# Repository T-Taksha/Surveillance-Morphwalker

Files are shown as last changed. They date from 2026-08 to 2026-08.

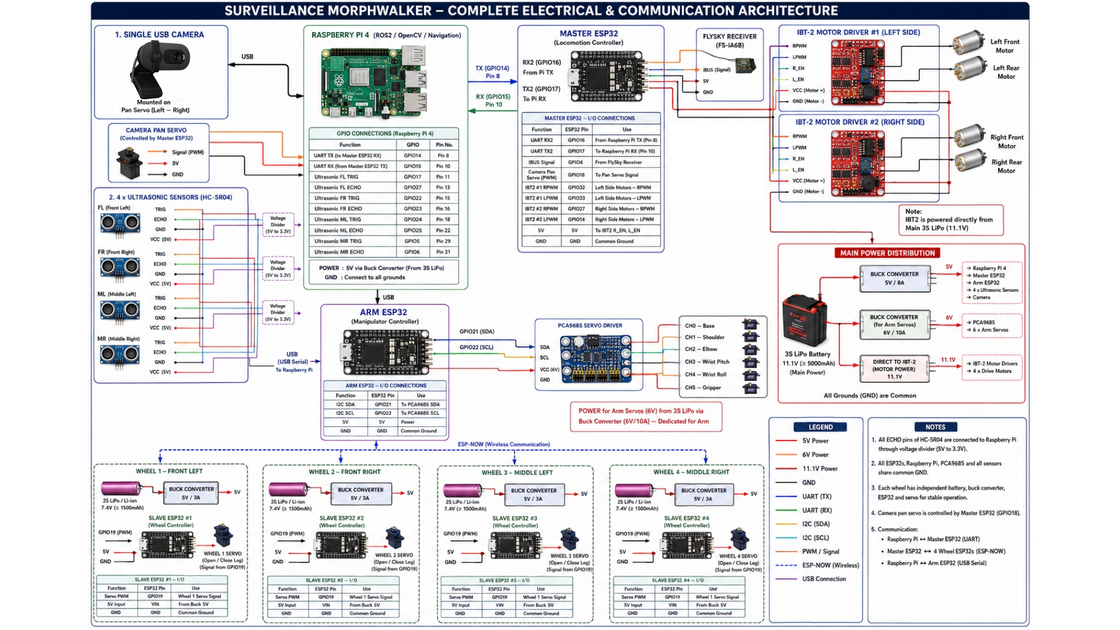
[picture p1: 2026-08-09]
Circuit Diagram.jpeg

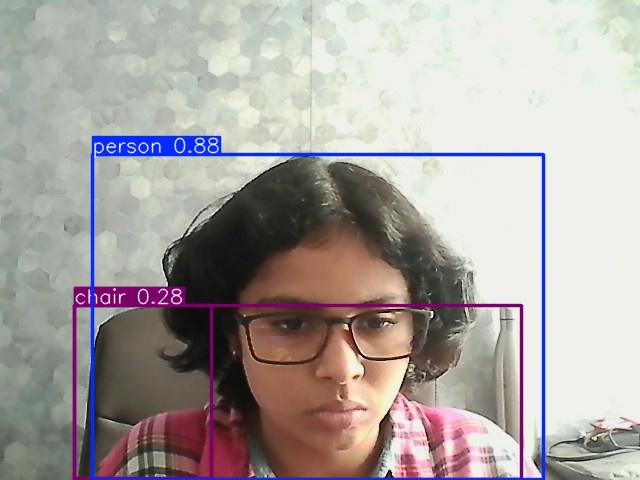
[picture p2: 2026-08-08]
last_detection.jpg

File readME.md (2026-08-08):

# Surveillance_Morphwalker

## A Transformable Wheel–Leg Hybrid Robot for Disaster Rescue and Surveillance

<p align="center">
  <b>One Robot. Two Locomotion Modes. Built for Mixed Terrain.</b>
</p>

---

## 📌 Overview

**Surveillance MorphWalker** is a compact transformable wheel–leg hybrid robot designed for **disaster rescue, surveillance, inspection, and hazardous-environment exploration**.

The robot combines the speed and efficiency of wheeled locomotion with the terrain adaptability of legged locomotion. It can transform between **wheel mode** and **leg mode** using a servo-actuated four-bar linkage mechanism, allowing it to adapt to different terrain conditions.

An onboard **Raspberry Pi 4** provides real-time vision processing and surveillance, while a distributed **ESP32-based control architecture** manages locomotion and mechanical transformation.

The system is designed as an affordable and locally maintainable robotic platform using commercially available components and 3D-printed structural parts.

---

## 🎯 Problem Statement

Disaster environments such as earthquakes, floods, landslides, and building collapses contain unstable and unpredictable terrain.

Conventional robotic platforms have important limitations:

* **Wheeled robots** are fast and efficient but struggle with rubble, steps, and uneven terrain.
* **Legged robots** can negotiate difficult terrain but are comparatively slow and complex.
* **Human rescuers** may be exposed to unstable structures, toxic environments, and other hazards during initial reconnaissance.
* Existing surveillance robots may provide visual information but lack adaptive locomotion and physical interaction capabilities.

Therefore, there is a need for a robotic platform that can:

* Traverse mixed and unpredictable terrain.
* Provide continuous visual surveillance.
* Adapt its locomotion according to terrain conditions.
* Reduce human exposure to hazardous environments.
* Remain affordable, repairable, and locally maintainable.

---

## 💡 Proposed Solution

MorphWalker addresses these challenges by combining two locomotion modes in a single robotic platform.

### 🛞 Wheel Mode

Used for:

* Flat terrain
* Semi-flat terrain
* Faster movement
* Efficient traversal

### 🦿 Leg Mode

Used for:

* Rubble
* Steps
* Uneven terrain
* Obstacles
* Rough surfaces

The robot uses a **servo-driven four-bar linkage mechanism** to transform the wheel structure into a leg configuration.

```text
              MORPHWALKER
                   │
          ┌────────┴────────┐
          │                 │
          ▼                 ▼
     WHEEL MODE         LEG MODE
          │                 │
     Fast movement     Obstacle traversal
     Flat terrain      Uneven terrain
          │                 │
          └────────┬────────┘
                   │
            Adaptive Mobility
```

---

## ⚙️ Key Features

* Transformable wheel–leg locomotion
* Servo-driven four-bar linkage mechanism
* Raspberry Pi 4 onboard processing
* Real-time camera surveillance
* OpenCV-based vision processing
* Object and obstacle detection
* Distributed ESP32 control architecture
* Wireless human-supervised operation
* Real-time video streaming
* 3D-printed mechanical components
* Modular design
* Low-cost and locally maintainable architecture

---

## 🏗️ System Architecture

The robot follows a hierarchical distributed architecture.

```text
                  ┌───────────────────┐
                  │      CAMERA       │
                  └─────────┬─────────┘
                            │
                            ▼
                  ┌───────────────────┐
                  │   RASPBERRY PI 4  │
                  │                   │
                  │ Vision Processing  │
                  │ Object Detection  │
                  │ Decision Making    │
                  │ Video Streaming    │
                  └─────────┬─────────┘
                            │
                            ▼
                  ┌───────────────────┐
                  │    MASTER ESP32   │
                  │                   │
                  │ Motion Coordinator│
                  └─────────┬─────────┘
                            │
              ┌─────────────┼─────────────┐
              │             │             │
              ▼             ▼             ▼
        ┌──────────┐  ┌──────────┐  ┌──────────┐
        │ Slave    │  │ Slave    │  │ Slave    │
        │ ESP32    │  │ ESP32    │  │ ESP32    │
        └────┬─────┘  └────┬─────┘  └────┬─────┘
             │             │             │
             └─────────────┼─────────────┘
                           │
                           ▼
                    Wheel Modules
```

### Raspberry Pi

The Raspberry Pi acts as the high-level processing unit.

Responsibilities include:

* Camera processing
* Object detection
* Video streaming
* High-level decision making
* Robot state monitoring
* Communication with the ESP32 control system

### Master ESP32

The Master ESP32 coordinates the low-level robotic system.

Responsibilities include:

* Receiving commands
* Coordinating locomotion
* Synchronizing wheel transformation
* Communicating with slave controllers

### Slave ESP32 Controllers

The slave controllers manage individual wheel modules.

Responsibilities include:

* DC motor control
* Servo control
* Wheel transformation
* Local actuator control

---

## 🔄 Wheel-to-Leg Transformation

Each wheel incorporates a **four-bar linkage mechanism** driven by a servo motor.

The transformation process changes the wheel from a compact circular configuration into an expanded leg-like configuration.

```text
WHEEL MODE
     ↓
Servo Actuation
     ↓
Linkage Expansion
     ↓
LEG MODE
```

When the terrain is suitable for wheeled traversal, the robot remains in wheel mode.

When an obstacle or uneven terrain is detected, the transformation mechanism can be activated to improve terrain adaptability.

---

## 👁️ Vision System

A camera connected to the Raspberry Pi provides real-time environmental information.

The vision pipeline uses **OpenCV** for image processing.

### Vision Pipeline

```text
Camera
   ↓
Frame Acquisition
   ↓
Image Preprocessing
   ↓
Edge / Contour Detection
   ↓
Obstacle Identification
   ↓
Terrain Assessment
   ↓
Movement / Transformation Decision
```

The system can perform:

* Real-time camera streaming
* Object detection
* Obstacle detection
* Terrain analysis
* Environmental monitoring

The project documentation reports an average vision-processing performance of approximately **18 FPS** during testing.

---

## 🧭 Autonomous Navigation

The navigation methodology uses environmental information to determine appropriate robot behavior.

### Basic decision logic

```text
              Environment
                   │
                   ▼
             Camera Input
                   │
                   ▼
           Terrain Assessment
                   │
        ┌──────────┼──────────┐
        │          │          │
        ▼          ▼          ▼
   Clear Path   Small       Large
                Obstacle    Obstacle
        │          │          │
        ▼          ▼          ▼
   Move Forward  Slow/     Transform
                 Re-route   to Leg Mode
```

The intended behavior is:

* Clear path → continue movement in wheel mode.
* Small obstacle → slow down or re-route.
* Large obstacle → activate wheel-to-leg transformation.
* Uneven terrain → prioritize leg mode for stability.

---

## 🎮 Control Modes

MorphWalker is designed around human-supervised robotic operation.

### Autonomous Mode

The robot uses environmental information for:

* Navigation
* Obstacle detection
* Locomotion decisions
* Transformation decisions

### Remote Control Mode

The operator controls the robot wirelessly.

### Surveillance Mode

The robot provides continuous visual monitoring while stationary or moving slowly.

---

## 🔧 Hardware Components

| Component | Purpose |
| --- | --- |
| Raspberry Pi 4 Model B | Central processing and control |
| ESP32 Master | Motion coordination |
| ESP32 Slave Controllers | Wheel-module control |
| MG995 Servo Motors | Wheel-leg transformation |
| DC Gear Motors | Locomotion |
| IBT-2 Motor Driver | Motor control |
| USB Camera | Visual surveillance |
| FlySky Transmitter | Wireless control |
| Li-Po Battery | Power supply |
| Buck Converter | Voltage regulation |
| PLA Filament | 3D-printed components |
| Bearings / Shafts / Fasteners | Mechanical assembly |

---

## 💻 Software Stack

| Software / Technology | Purpose |
| --- | --- |
| Python | Control and vision programming |
| C++ / Embedded C | ESP32 control |
| OpenCV | Computer vision |
| YOLO | Object detection |
| Raspberry Pi OS / Ubuntu | Computing platform |
| Arduino IDE | ESP32 development |
| Fusion 360 / SolidWorks  | CAD design |
| Git | Version control |
| GitHub | Project repository |

---

## 📊 Prototype Specifications

| Parameter | Specification |
| --- | ---: |
| Transformation time |  ~2–3 seconds |
| Average transformation time |  ~2.7 seconds |
| Vision processing | ~18 FPS |
| Weight | 3–5 kg |
| Typical mixed-operation runtime | ~28 minutes |
| Continuous wheeled operation | ~35 minutes |
| Continuous legged operation | ~22 minutes |
| Structure | 3D-printed |
| Primary material | PLA |

---

## 🧪 Experimental Results

The prototype was evaluated for transformation, vision processing, autonomous navigation, and power performance.

### Mechanical Transformation

* Average transformation time: **2.7 ± 0.3 seconds**
* Minimum transformation time: **2.2 seconds**
* Maximum transformation time: **3.4 seconds**
* Test cycles: **20**

### Vision Processing

* Average processing rate: **18 FPS**
* Processing latency: approximately **65 ± 8 ms**

### Obstacle Detection

| Obstacle Type | Detection Accuracy |
| --- | ---: |
| Vertical Walls | 98% |
| Steps & Curbs | 96% |
| Small Objects | 92% |
| Irregular Terrain | 89% |

### Autonomous Navigation

| Test Section | Success Rate |
| --- | ---: |
| Flat Surface | 100% |
| Incline | 100% |
| Obstacle Field  | 90% |
| Rough Terrain | 80% |
| Combined Course | 85% |

---

## 🔋 Power Performance

Using the tested 12 V, 3300 mAh Li-Po battery:

| Operating Condition | Runtime |
| --- | ---: |
| Continuous wheel mode | ~35 min |
| Continuous leg mode | ~22 min |
| Typical mixed operation | ~28 min |
| Intermittent operation  | 45+ min |

---

## 🧩 Project Development Phases

### Phase 1 — Design

* Requirement definition
* Mechanical design
* CAD modelling
* Component selection
* Software architecture

### Phase 2 — Fabrication

* 3D printing
* Mechanical assembly
* Electronics integration
* Wiring
* Initial testing

### Phase 3 — Integration

* ESP32 control
* Raspberry Pi integration
* Camera integration
* Vision processing
* Locomotion integration
* Transformation testing

### Phase 4 — Autonomous Operation

* Environmental perception
* Obstacle detection
* Decision making
* Adaptive locomotion
* Autonomous transformation

### Phase 5 — Future Development

* Advanced perception
* Sensor fusion
* SLAM
* Environmental sensing
* Multi-robot coordination

---

## 🚀 Future Scope

The platform can be extended with:

* LiDAR-based SLAM
* Thermal cameras
* Gas and chemical sensors
* Depth cameras
* IMU integration
* Advanced terrain classification
* Improved autonomous navigation
* Multi-robot coordination
* Waterproofing
* Ruggedized mechanical components
* Energy optimization
* Autonomous mission planning

---

## 🌍 Applications

MorphWalker can be adapted for:

### Disaster Response

* Earthquake reconnaissance
* Building-collapse inspection
* Landslide response
* Flood-zone inspection

### Industrial Inspection

* Hazardous-area inspection
* Gas/chemical environments
* Confined-space inspection
* Infrastructure monitoring

### Surveillance

* Remote surveillance
* Perimeter monitoring
* Continuous visual inspection

### Environmental Exploration

* Difficult terrain exploration
* Remote environmental monitoring
* Hazardous-zone reconnaissance

---

## ⚠️ Current Limitations

The current prototype has several limitations:

* Limited battery endurance
* Prototype-scale mechanical construction
* Limited field testing
* Vision performance can be affected by low-light or smoky environments
* Full autonomous navigation requires further development
* Self-righting capability is not currently implemented
* Additional environmental sensors are required for advanced disaster-response applications

---

## 📁 Repository Structure

```text
Surveillance-MorphWalker/
│
├── README.md
│
├── hardware/
│   ├── esp32/
│   ├── motors/
│   ├── servos/
│   └── wiring/
│
├── software/
│   ├── vision/
│   ├── navigation/
│   ├── control/
│   └── streaming/
│
├── mechanical/
│   ├── chassis/
│   ├── wheel-leg/
│   └── assemblies/
│
├── cad/
│
├── documentation/
│
├── images/
│
└── tests/
```

---

## 👥 Project Team

**Department of Robotics and Artificial Intelligence**
**Bangalore Institute of Technology, Bengaluru**

| Team Member | Role |
| --- | --- |
| **Taksha Tangudu** | ROS2 & Gazebo Simulation, Robotic Arm and Wheel CAD Design, ESP32 Master–Slave Control |
| **Vijhortha VS** | Computer Vision & Perception, Raspberry Pi Programming |
| **Raja R** | Electronics Management, Mechanical Assembly of Robot and Arm |
| **Varun V** | Mechanism Design, Robot & Arm Assembly, System Architecture Design |

### Project Guide

**Prof. Sunitha M. K.**
Assistant Professor
Department of Robotics and Artificial Intelligence
Bangalore Institute of Technology

---

## 📚 References

1. R. Cao, J. Gu, C. Yu, and A. Rosendo, *"OmniWheg: An Omnidirectional Wheel-Leg Transformable Robot,"* IEEE/RSJ International Conference on Intelligent Robots and Systems (IROS), 2022.

2. L. Bai, X. Li, Y. Sun, J. Zheng, and X. Chen, *"A Wheel-Legged Mobile Robot with Adjustable Body Length for Rescue and Search,"* IEEE International Conference on Advanced Robotics and Mechatronics, 2021.

3. B. Katz, J. D. Carlo, and S. Kim, *"Mini Cheetah: A Platform for Pushing the Limits of Dynamic Quadruped Control,"* IEEE International Conference on Robotics and Automation, 2019.

4. I. Mertyuz, A. K. Tanyıldızı, B. Taşar, A. B. Tatar, and O. Yakut, *"Fuhar: A Transformable Wheel-Legged Hybrid Mobile Robot,"* Robotics and Autonomous Systems, 2020.

5. W.-H. Chen, H.-S. Lin, Y.-M. Lin, and P.-C. Lin, *"TurboQuad: A Novel Leg–Wheel Transformable Robot with Smooth and Fast Behavioral Transitions,"* IEEE Transactions on Robotics, 2017.

6. Y.-S. Kim et al., *"Wheel Transformer: A Wheel-Leg Hybrid Robot with Passive Transformable Wheels,"* IEEE Transactions on Robotics, 2014.

7. G. Bradski, *"The OpenCV Library,"* Dr. Dobb's Journal of Software Tools, 2000.

---

## 📄 License

This project is developed for **academic, research, and educational purposes**.

The licensing terms for source code, CAD files, and hardware designs will be defined as the project repository is prepared for public release.

---

## ⭐ Vision

> **MorphWalker is designed to put a robot where humans should not have to go first.**

By combining adaptive locomotion, real-time surveillance, and intelligent decision-making, MorphWalker aims to provide a safer and more versatile platform for inspection and disaster-response robotics.

---

# 🤖 Surveillance MorphWalker

### **Adaptive Mobility • Real-Time Surveillance • Intelligent Robotics**

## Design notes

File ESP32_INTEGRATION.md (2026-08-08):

# ESP32 Wheel-to-Leg Transformation Integration

## Overview

Your Raspberry Pi robot now supports ESP32-based wheel-to-leg transformation! The system communicates with your Master ESP32 via Serial/UART, which then controls 4 slave ESP32s using ESP-NOW.

## Hardware Setup

### Wiring Connection

Connect Raspberry Pi to ESP32 Master:

**Option 1: GPIO UART (Recommended)**
```
Raspberry Pi GPIO Pin 14 (TX)  →  ESP32 RX (GPIO 16 or RXD0)
Raspberry Pi GPIO Pin 15 (RX)  →  ESP32 TX (GPIO 17 or TXD0)
Raspberry Pi GND              →  ESP32 GND
```

**Option 2: USB-to-Serial**
- Connect USB cable from Raspberry Pi to ESP32
- Port will be `/dev/ttyUSB0` or `/dev/ttyACM0`

### ESP32 Configuration

Your existing ESP32 master code needs to be modified to receive commands from Raspberry Pi. Add this to your ESP32 master setup:

```cpp
// In setup()
Serial.begin(115200);  // Must match Raspberry Pi baud rate
```

Add command parsing to your ESP32 master loop:

```cpp
// In loop()
if (Serial.available() > 0) {
  String jsonString = Serial.readStringUntil('\n');
  
  // Parse JSON: {"cmd": 1, "speed": 100}
  // Extract cmd and speed, then broadcast to slaves
  // cmd: 0=STOP, 1=OPEN, 2=CLOSE
}
```

## Usage

### 1. Testing ESP32 Communication

Test the ESP32 connection:
```bash
cd "/c/VS Code/Mini Project - anti"
python utils/esp32_comm.py
```

This will:
- Connect to ESP32 on `/dev/serial0`
- Send OPEN command (speed 100)
- Wait 5 seconds
- Send CLOSE command (speed 100)

**Troubleshooting:**
- If connection fails, try different ports: `/dev/ttyUSB0`, `/dev/ttyACM0`, `COM3` (Windows)
- Check ESP32 is powered on and Serial baud rate matches (115200)
- Verify wiring connections

### 2. Using in Object Detection Mode

The transformation automatically triggers when objects are detected close to the robot:

```bash
python main.py --mode autonomous --detection --enable-esp32
```

Features:
- Automatically opens wheels→legs when object detected within 30cm
- Closes legs→wheels after 3 seconds
- Customizable trigger distance in `object_action_handler.py`

### 3. Manual Control via Web Interface

Start the robot with ESP32 enabled:
```bash
python main.py --mode stream --enable-esp32
```

Then:
1. Open browser: `http://<raspberry-pi-ip>:5000`
2. Use the "🔧 Wheels→Legs" button to open
3. Use the "🔧 Legs→Wheels" button to close

### 4. Custom Port Configuration

If using USB-to-Serial adapter:
```bash
python main.py --enable-esp32 --esp32-port /dev/ttyUSB0
```

## Python API Usage

### Direct Control

```python
from utils.esp32_comm import ESP32Controller

# Create controller
esp32 = ESP32Controller(port='/dev/serial0', baudrate=115200)

# Open wheels (transform to legs)
esp32.open_wheels(speed=100)
time.sleep(3)

# Close wheels (transform back)
esp32.close_wheels(speed=100)

# Stop transformation
esp32.stop()

# Check status
status = esp32.get_status()
print(f"Connected: {status['connected']}")

# Cleanup
esp32.cleanup()
```

### Integration in Your Code

```python
from object_action_handler import ObjectActionHandler
from motor_control import MotorController

# Initialize with ESP32
motor = MotorController()
handler = ObjectActionHandler(
    motor_controller=motor,
    enable_esp32=True,
    esp32_port='/dev/serial0'
)

# Transformation will automatically trigger on object detection
# Or manually trigger:
handler.esp32.open_wheels(speed=100)
```

## Configuration

### Speed Control
Adjust transformation speed (0-100):
```python
esp32.open_wheels(speed=50)   # Slower transformation
esp32.close_wheels(speed=100) # Faster transformation
```

### Trigger Distance
Edit `object_action_handler.py`:
```python
TRANSFORMATION_TRIGGER_DISTANCE = 30  # cm - change this value
```

### Transformation Duration
Edit `object_action_handler.py`:
```python
TRANSFORMATION_DURATION = 3.0  # seconds - auto-close timer
```

## Command Protocol

Raspberry Pi sends JSON commands via Serial:

**OPEN Command:**
```json
{"cmd": 1, "speed": 100}
```

**CLOSE Command:**
```json
{"cmd": 2, "speed": 100}
```

**STOP Command:**
```json
{"cmd": 0, "speed": 0}
```

ESP32 Master should:
1. Parse JSON from Serial
2. Extract `cmd` and `speed`
3. Broadcast to 4 slaves via ESP-NOW
4. (Optional) Send acknowledgment back to Raspberry Pi

## Files Modified

| File | Changes |
|---|---|
| `utils/esp32_comm.py` | **NEW** - ESP32 Serial communication module |
| `object_action_handler.py` | Replaced GPIO servo control with ESP32 commands |
| `main.py` | Added ESP32 web controls and initialization |
| `controller.py` | No changes needed (future enhancement for terrain-based transformation) |

## Next Steps

1. **Modify ESP32 Master Code**: Add JSON parsing to receive commands from Raspberry Pi
2. **Test Communication**: Run `python utils/esp32_comm.py` to verify
3. **Full System Test**: Run with `--enable-esp32` flag
4. **Adjust Parameters**: Tune speed, trigger distance, and duration

## Support

If you encounter issues:
- Check Serial port permissions: `sudo usermod -a -G dialout $USER`
- Verify ESP32 baud rate matches (115200)
- Monitor ESP32 Serial output in Arduino IDE
- Check physical wiring connections

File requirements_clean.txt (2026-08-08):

# ============================================================
# Core Dependencies (Required)
# ============================================================
opencv-python>=4.5.0
numpy>=1.19.0
flask>=2.0.0
imutils>=0.5.4

# RPi.GPIO - Required for Raspberry Pi (will fail on Windows - use mock)
RPi.GPIO>=0.7.0; platform_machine == "armv7l" or platform_machine == "aarch64"

# ============================================================
# Object Detection (Recommended)
# ============================================================
ultralytics>=8.0.0  # YOLO v8 for object detection
torch>=1.9.0        # PyTorch (required by ultralytics)

# ============================================================
# Optional Dependencies
# ============================================================
flask-cors>=3.0.10  # CORS support for web interface
Pillow>=8.0.0       # Image processing
requests>=2.25.0    # HTTP requests
pandas>=1.2.0       # Data handling (optional)

# ============================================================
# Development/Testing (Optional)
# ============================================================
matplotlib>=3.3.0   # Visualization for debugging

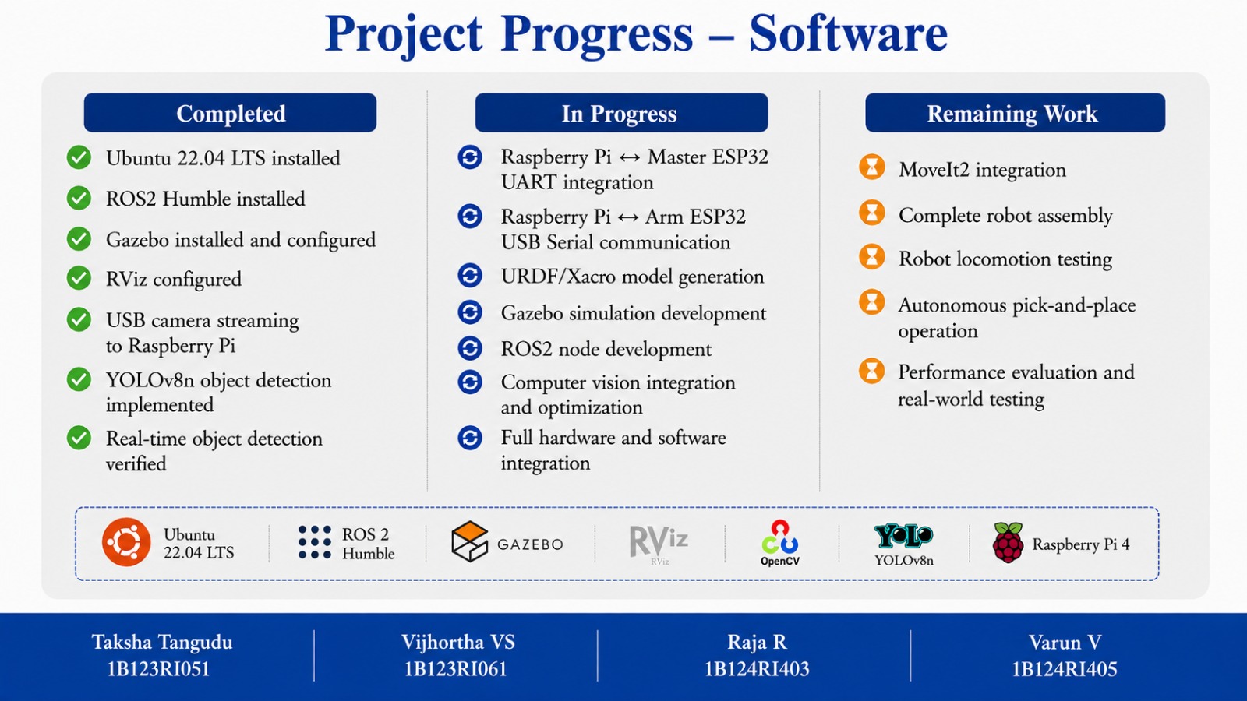
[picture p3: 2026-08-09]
Project_In_Progress.jpeg

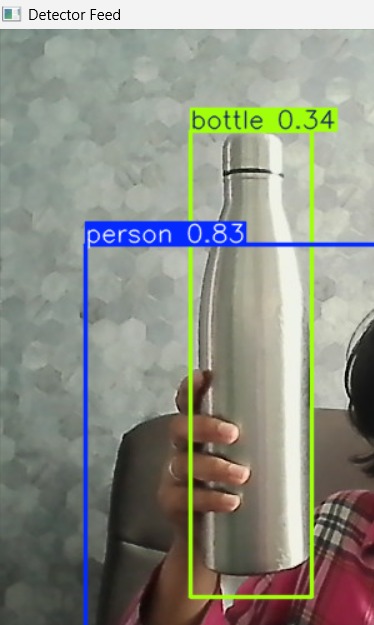
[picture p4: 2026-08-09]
Pictures_Morphwalker/Object_Detection.jpeg

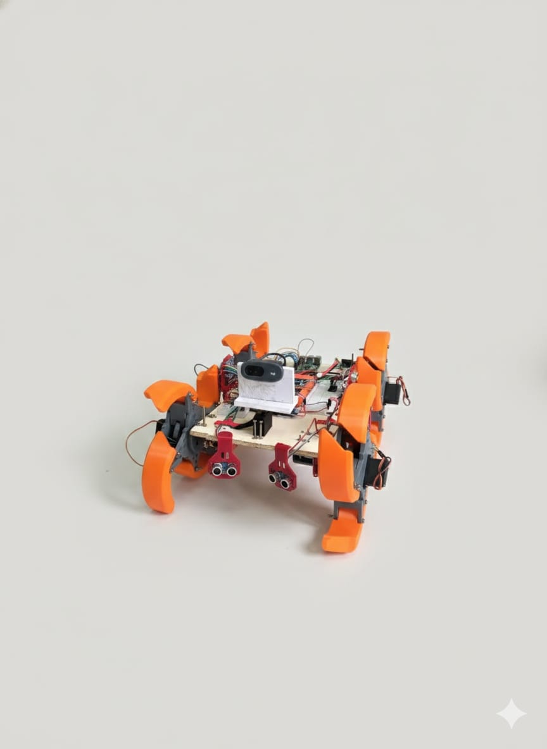
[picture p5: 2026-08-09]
Pictures_Morphwalker/Morphwalker_Leg_Mode.jpeg

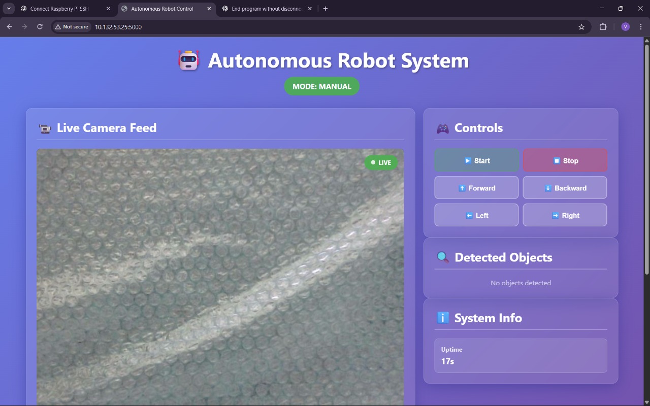
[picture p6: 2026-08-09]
Pictures_Morphwalker/Live_Camera_feed.jpeg

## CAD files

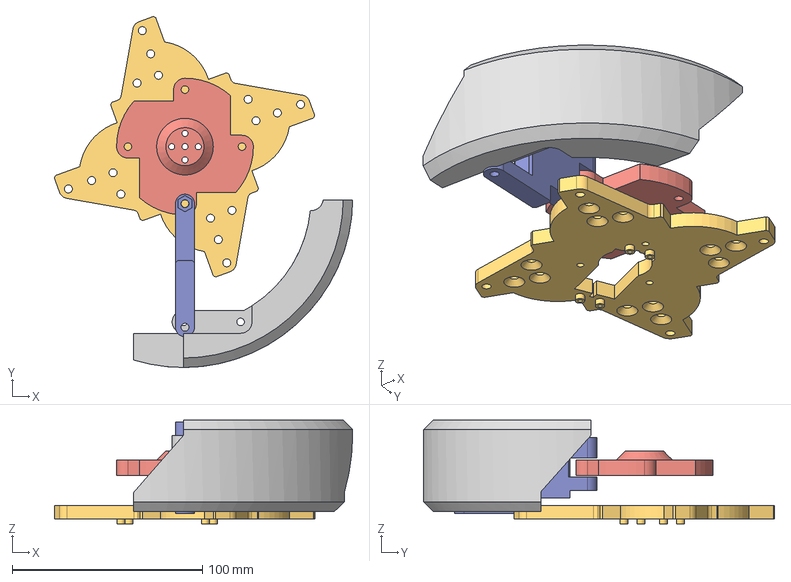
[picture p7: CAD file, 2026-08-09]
FUSION/assembly.step
157.0 x 184.7 x 54.6 mm
零部件10
零部件9
零部件8(镜像)
tyre taks

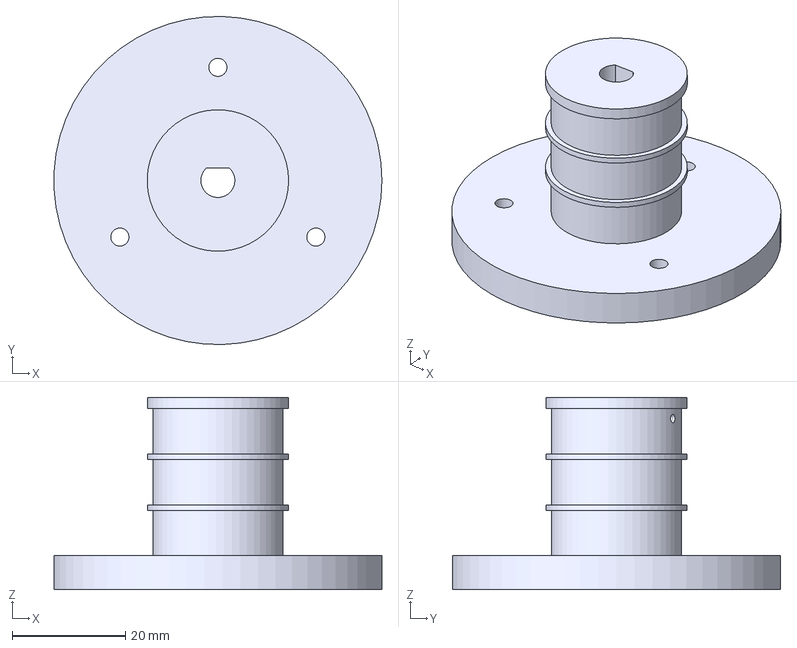
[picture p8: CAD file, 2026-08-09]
FUSION/COUPLING_CUSTOM.step
58.0 x 58.0 x 34.0 mm

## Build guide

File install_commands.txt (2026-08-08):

# ============================================================
# Direct Installation Commands for Conda Environment
# ============================================================
# Copy and paste these commands one by one into your terminal
# Make sure 'myenv' conda environment is activated first!
# ============================================================

# Step 1: Activate your conda environment (if not already active)
conda activate myenv

# Step 2: Install core packages via conda
conda install -y opencv numpy flask

# Step 3: Install additional packages via pip
pip install imutils flask-cors

# Step 4: Install RPi.GPIO (will fail on Windows - that's OK)
pip install RPi.GPIO

# Step 5: Install YOLO for object detection (optional, large download)
pip install ultralytics

# Step 6: Verify installation
python -c "import cv2, numpy, flask; print('✓ All core packages installed successfully!')"

# ============================================================
# Alternative: Install everything at once
# ============================================================
pip install opencv-python numpy flask imutils flask-cors ultralytics

# ============================================================
# Minimal Installation (if you want to skip YOLO)
# ============================================================
pip install opencv-python numpy flask imutils flask-cors

# ============================================================
# Check what's installed
# ============================================================
pip list | findstr "opencv numpy flask ultralytics imutils"

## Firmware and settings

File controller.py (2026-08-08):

"""
controller.py

Autonomous robot controller using 3 ultrasonic sensors for obstacle avoidance.

Sensor Configuration:
- Front sensor: Detects obstacles ahead
- Left sensor: Detects obstacles on the left side
- Right sensor: Detects obstacles on the right side

Movement Logic:
- If all paths are clear → Move forward
- If obstacle ahead but sides clear → Turn towards clearer side
- If obstacle on one side → Turn away from obstacle
- If obstacles on all sides → Reverse and turn

Hardware:
- 3x HC-SR04 Ultrasonic Sensors
- Motor driver (L298N or BTS IBT_2)
- Raspberry Pi 4

Author: Auto-generated
"""

import time
import threading
from typing import Optional, Callable
from utils.gpio_helper import MotorDriver, UltrasonicSensor, GPIOHelper

# ========== CONFIGURATION ==========
# Distance thresholds (in centimeters)
SAFE_DISTANCE = 30          # Minimum safe distance from obstacles
CRITICAL_DISTANCE = 15      # Critical distance requiring immediate action
TURN_DISTANCE = 40          # Distance to start turning

# Movement speeds (0-100)
NORMAL_SPEED = 40           # Normal forward speed
TURN_SPEED = 35             # Speed while turning
REVERSE_SPEED = 55          # Speed while reversing

# Timing (in seconds)
SENSOR_READ_INTERVAL = 0.1  # How often to read sensors
TURN_DURATION = 0.5         # Duration of turn maneuvers
REVERSE_DURATION = 0.8      # Duration of reverse maneuvers

# Motor pins (adjust based on your wiring)
MOTOR_IN1 = 17
MOTOR_IN2 = 27
MOTOR_ENA = 18
MOTOR_IN3 = 22
MOTOR_IN4 = 23
MOTOR_ENB = 24

# Ultrasonic sensor pins (from CSV configuration)
FRONT_TRIGGER_1 = 20
FRONT_ECHO_1 = 21
FRONT_TRIGGER_2 = 7
FRONT_ECHO_2 = 8
LEFT_TRIGGER = 1
LEFT_ECHO = 4
RIGHT_TRIGGER = 23
RIGHT_ECHO = 9

# ===================================


class RobotController:
    """
    Main controller for autonomous robot navigation using ultrasonic sensors.
    
    Features:
    - Continuous sensor monitoring
    - Intelligent obstacle avoidance
    - Configurable movement behaviors
    - Safe shutdown handling
    """
    
    def __init__(self,
                 motor_pins: dict = None,
                 sensor_pins: dict = None,
                 safe_distance: float = SAFE_DISTANCE,
                 critical_distance: float = CRITICAL_DISTANCE,
                 normal_speed: int = NORMAL_SPEED):
        """
        Initialize the robot controller.
        
        Args:
            motor_pins: Dict with keys 'in1', 'in2', 'ena', 'in3', 'in4', 'enb'
            sensor_pins: Dict with keys 'front', 'left', 'right' (each containing 'trigger', 'echo')
            safe_distance: Minimum safe distance from obstacles (cm)
            critical_distance: Critical distance requiring immediate action (cm)
            normal_speed: Default forward speed (0-100)
        """
        # Setup GPIO
        GPIOHelper.set_mode()
        
        # Initialize motor driver
        if motor_pins is None:
            motor_pins = {
                'in1': MOTOR_IN1, 'in2': MOTOR_IN2, 'ena': MOTOR_ENA,
                'in3': MOTOR_IN3, 'in4': MOTOR_IN4, 'enb': MOTOR_ENB
            }
        
        self.motor = MotorDriver(**motor_pins)
        
        # Initialize ultrasonic sensors
        if sensor_pins is None:
            sensor_pins = {
                'front1': {'trigger': FRONT_TRIGGER_1, 'echo': FRONT_ECHO_1},
                'front2': {'trigger': FRONT_TRIGGER_2, 'echo': FRONT_ECHO_2},
                'left': {'trigger': LEFT_TRIGGER, 'echo': LEFT_ECHO},
                'right': {'trigger': RIGHT_TRIGGER, 'echo': RIGHT_ECHO}
            }
        
        self.sensor_front1 = UltrasonicSensor(
            trigger_pin=sensor_pins['front1']['trigger'],
            echo_pin=sensor_pins['front1']['echo']
        )
        self.sensor_front2 = UltrasonicSensor(
            trigger_pin=sensor_pins['front2']['trigger'],
            echo_pin=sensor_pins['front2']['echo']
        )
        self.sensor_left = UltrasonicSensor(
            trigger_pin=sensor_pins['left']['trigger'],
            echo_pin=sensor_pins['left']['echo']
        )
        self.sensor_right = UltrasonicSensor(
            trigger_pin=sensor_pins['right']['trigger'],
            echo_pin=sensor_pins['right']['echo']
        )
        
        # Configuration
        self.safe_distance = safe_distance
        self.critical_distance = critical_distance
        self.normal_speed = normal_speed
        
        # State
        self._running = False
        self._control_thread: Optional[threading.Thread] = None
        self._last_distances = {'front': 999, 'left': 999, 'right': 999}
        
        # Callbacks
        self.on_obstacle_detected: Optional[Callable[[str, float], None]] = None
        self.on_state_change: Optional[Callable[[str], None]] = None
        
        print("[Controller] Initialized with 3 ultrasonic sensors")
        print(f"[Controller] Safe distance: {safe_distance}cm, Critical: {critical_distance}cm")
    
    def read_sensors(self) -> dict:
        """
        Read all ultrasonic sensors and return distances.
        
        Returns:
            Dict with keys 'front1', 'front2', 'left', 'right' containing distances in cm
        """
        distances = {
            'front1': self.sensor_front1.get_distance_cm(),
            'front2': self.sensor_front2.get_distance_cm(),
            'left': self.sensor_left.get_distance_cm(),
            'right': self.sensor_right.get_distance_cm()
        }
        
        # Store for reference
        self._last_distances = distances
        
        return distances
    
    def decide_action(self, distances: dict) -> str:
        """
        Decide what action to take based on sensor readings.
        
        Args:
            distances: Dict with 'front1', 'front2', 'left', 'right' distances
        
        Returns:
            Action string: 'forward', 'turn_left', 'turn_right', 'reverse', 'stop'
        """
        # Use the minimum of the two front sensors as the effective front distance
        front = min(distances['front1'], distances['front2'])
        left = distances['left']
        right = distances['right']
        
        # Critical obstacle ahead - immediate action required
        if front < self.critical_distance:
            if left > right:
                return 'turn_left'
            else:
                return 'turn_right'
        
        # Obstacle ahead but not critical
        if front < self.safe_distance:
            # Check which side has more space
            if left > self.safe_distance and right > self.safe_distance:
                # Both sides clear, turn towards the side with more space
                return 'turn_left' if left > right else 'turn_right'
            elif left > self.safe_distance:
                return 'turn_left'
            elif right > self.safe_distance:
                return 'turn_right'
            else:
                # Both sides blocked, reverse
                return 'reverse'
        
        # Obstacle on left side
        if left < self.safe_distance and front > self.safe_distance:
            return 'turn_right'
        
        # Obstacle on right side
        if right < self.safe_distance and front > self.safe_distance:
            return 'turn_left'
        
        # All clear - move forward
        if front > self.safe_distance:
            return 'forward'
        
        # Default: stop
        return 'stop'
    
    def execute_action(self, action: str):
        """
        Execute the decided action.
        
        Args:
            action: Action string from decide_action()
        """
        if action == 'forward':
            self.motor.forward(speed=self.normal_speed)
            if self.on_state_change:
                self.on_state_change('forward')
        
        elif action == 'turn_left':
            self.motor.left(speed=TURN_SPEED)
            if self.on_state_change:
                self.on_state_change('turn_left')
            time.sleep(TURN_DURATION)
        
        elif action == 'turn_right':
            self.motor.right(speed=TURN_SPEED)
            if self.on_state_change:
                self.on_state_change('turn_right')
            time.sleep(TURN_DURATION)
        
        elif action == 'reverse':
            self.motor.backward(speed=REVERSE_SPEED)
            if self.on_state_change:
                self.on_state_change('reverse')
            time.sleep(REVERSE_DURATION)
            # After reversing, turn to find clear path
            if self._last_distances['left'] > self._last_distances['right']:
                self.motor.left(speed=TURN_SPEED)
                time.sleep(TURN_DURATION)
            else:
                self.motor.right(speed=TURN_SPEED)
                time.sleep(TURN_DURATION)
        
        elif action == 'stop':
            self.motor.stop()
            if self.on_state_change:
                self.on_state_change('stop')
    
    def _control_loop(self):
        """
        Main control loop running in background thread.
        Continuously reads sensors and executes appropriate actions.
        """
        print("[Controller] Control loop started")
        
        while self._running:
            try:
                # Read all sensors
                distances = self.read_sensors()
                
                # Log sensor readings (optional, comment out for less verbosity)
                # print(f"[Sensors] Front: {distances['front']:.1f}cm, "
                #       f"Left: {distances['left']:.1f}cm, "
                #       f"Right: {distances['right']:.1f}cm")
                
                # Trigger obstacle detection callbacks
                if self.on_obstacle_detected:
                    for direction, distance in distances.items():
                        if distance < self.safe_distance:
                            self.on_obstacle_detected(direction, distance)
                
                # Decide action based on sensor data
                action = self.decide_action(distances)
                
                # Execute the action
                self.execute_action(action)
                
                # Small delay before next iteration
                time.sleep(SENSOR_READ_INTERVAL)
                
            except Exception as e:
                print(f"[Controller] Error in control loop: {e}")
                self.motor.stop()
                time.sleep(0.5)
        
        # Stop motors when loop exits
        self.motor.stop()
        print("[Controller] Control loop stopped")
    
    def start(self):
        """Start autonomous navigation."""
        if self._running:
            print("[Controller] Already running")
            return
        
        self._running = True
        self._control_thread = threading.Thread(target=self._control_loop, daemon=True)
        self._control_thread.start()
        print("[Controller] Autonomous navigation started")
    
    def stop(self):
        """Stop autonomous navigation."""
        if not self._running:
            return
        
        print("[Controller] Stopping autonomous navigation...")
        self._running = False
        
        if self._control_thread:
            self._control_thread.join(timeout=2.0)
        
        self.motor.stop()
        print("[Controller] Stopped")
    
    def get_status(self) -> dict:
        """
        Get current robot status.
        
        Returns:
            Dict with current distances and running state
        """
        return {
            'running': self._running,
            'distances': self._last_distances.copy(),
            'safe_distance': self.safe_distance,
            'critical_distance': self.critical_distance
        }
    
    def cleanup(self):
        """Clean up resources and stop all operations."""
        print("[Controller] Cleaning up...")
        self.stop()
        self.motor.cleanup()
        GPIOHelper.cleanup()
        print("[Controller] Cleanup complete")


# ========== DEMO / TESTING ==========
if __name__ == '__main__':
    """
    Demo usage of the robot controller.
    Run this script directly to test autonomous navigation.
    """
    import signal
    import sys
    
    # Create controller instance
    controller = RobotController()
    
    # Optional: Add callbacks for monitoring
    def on_obstacle(direction: str, distance: float):
        print(f"[!] Obstacle detected: {direction} at {distance:.1f}cm")
    
    def on_state(state: str):
        print(f"[Robot] State: {state}")
    
    controller.on_obstacle_detected = on_obstacle
    controller.on_state_change = on_state
    
    # Handle Ctrl+C for graceful shutdown
    def signal_handler(sig, frame):
        print("\n[Main] Interrupt received, shutting down...")
        controller.cleanup()
        sys.exit(0)
    
    signal.signal(signal.SIGINT, signal_handler)
    
    try:
        print("=" * 50)
        print("AUTONOMOUS ROBOT CONTROLLER")
        print("=" * 50)
        print(f"Safe Distance: {SAFE_DISTANCE}cm")
        print(f"Critical Distance: {CRITICAL_DISTANCE}cm")
        print(f"Normal Speed: {NORMAL_SPEED}%")
        print("=" * 50)
        print("\nStarting autonomous navigation...")
        print("Press Ctrl+C to stop\n")
        
        # Start autonomous navigation
        controller.start()
        
        # Keep main thread alive and print status periodically
        while True:
            time.sleep(5)
            status = controller.get_status()
            d = status['distances']
            print(f"\n[Status] Front1={d['front1']:.1f}cm, Front2={d['front2']:.1f}cm, "
                  f"Left={d['left']:.1f}cm, Right={d['right']:.1f}cm")
    
    except KeyboardInterrupt:
        print("\n[Main] Keyboard interrupt")
    
    finally:
        controller.cleanup()
        print("[Main] Goodbye!")

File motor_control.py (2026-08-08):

"""
motor_control.py

Controls robot movement using L298N or BTS IBT_2 motor driver and Raspberry Pi GPIO pins.

This module provides a high-level interface for controlling a differential drive robot.
It supports both L298N and BTS IBT_2 motor drivers with configurable pins and speeds.

Features:
- Forward, backward, left, right, and stop movements
- Speed control using PWM (0-100%)
- Configurable motor driver type (L298N or IBT)
- Safe cleanup and GPIO management
- Smooth acceleration/deceleration (optional)

Hardware Compatibility:
- L298N Motor Driver: Uses IN1, IN2, ENA, IN3, IN4, ENB pins
- BTS IBT_2 Motor Driver: Uses RPWM and LPWM pins for each motor

Usage:
    from motor_control import MotorController
    
    # Using L298N driver
    motor = MotorController(driver_type='L298N')
    motor.forward(speed=70)
    motor.left(speed=50)
    motor.stop()
    motor.cleanup()
    
    # Using IBT driver
    motor = MotorController(driver_type='IBT', 
                           m1_rpwm=12, m1_lpwm=13, 
                           m2_rpwm=18, m2_lpwm=19)
    motor.forward(speed=60)
    motor.cleanup()

Author: Auto-generated for Raspberry Pi Robot Project
"""

import time
from typing import Optional, Literal
from utils.gpio_helper import MotorDriver, IBTMotorDriver, GPIOHelper

# ========== CONFIGURATION ==========
# Default L298N pins (adjust based on your wiring)
DEFAULT_L298N_PINS = {
    'in1': 17,
    'in2': 27,
    'ena': 18,
    'in3': 22,
    'in4': 23,
    'enb': 24
}

# Default IBT pins (from CSV configuration)
DEFAULT_IBT_PINS = {
    'm1_rpwm_pin': 17,  # Driver 1 Motor A RPWM
    'm1_lpwm_pin': 27,  # Driver 1 Motor A LPWM
    'm2_rpwm_pin': 6,   # Driver 2 Motor A RPWM
    'm2_lpwm_pin': 13,  # Driver 2 Motor A LPWM
    'm1_r_en_pin': 22,  # Driver 1 R_EN
    'm1_l_en_pin': 5,   # Driver 1 L_EN
    'm2_r_en_pin': 19,  # Driver 2 R_EN
    'm2_l_en_pin': 26   # Driver 2 L_EN
}

# Default speeds (0-100)
DEFAULT_FORWARD_SPEED = 40
DEFAULT_TURN_SPEED = 35
DEFAULT_REVERSE_SPEED = 55

# PWM frequency (Hz)
DEFAULT_PWM_FREQ = 1000

# Acceleration settings
ENABLE_SMOOTH_ACCELERATION = False
ACCELERATION_STEP = 5  # Speed increment per step
ACCELERATION_DELAY = 0.05  # Delay between steps (seconds)

# ===================================


class MotorController:
    """
    High-level motor controller for differential drive robots.
    
    Supports both L298N and BTS IBT_2 motor drivers with a unified interface.
    Provides movement functions: forward, backward, left, right, stop.
    
    IBT-2 Hardware Configuration (from hardware table):
    Driver 1 (Left Side): RPWM=GPIO17, LPWM=GPIO27, R_EN=GPIO22, L_EN=GPIO5
    Driver 2 (Right Side): RPWM=GPIO6, LPWM=GPIO13, R_EN=GPIO19, L_EN=GPIO26
    
    Motor Movement Logic (for IBT-2 differential drive):
    Forward: M1(+), M2(+) - Both sides move forward
    Backward: M1(-), M2(-) - Both sides move backward
    Left: M1(-), M2(+) - Left reverses, right forward (pivot left)
    Right: M1(+), M2(-) - Left forward, right reverses (pivot right)
    
    Attributes:
        driver_type: Type of motor driver ('L298N' or 'IBT')
        current_speed: Current speed setting (0-100)
        is_moving: Whether the robot is currently moving
    """
    
    def __init__(self, 
                 driver_type: Literal['L298N', 'IBT'] = 'L298N',
                 **kwargs):
        """
        Initialize the motor controller.
        
        Args:
            driver_type: Type of motor driver ('L298N' or 'IBT')
            **kwargs: Pin configuration for the selected driver
                     For L298N: in1, in2, ena, in3, in4, enb
                     For IBT: m1_rpwm_pin, m1_lpwm_pin, m2_rpwm_pin, m2_lpwm_pin
        """
        self.driver_type = driver_type
        self.current_speed = 0
        self.is_moving = False
        self._target_speed = 0
        
        # Setup GPIO mode
        GPIOHelper.set_mode()
        
        # Initialize the appropriate motor driver
        if driver_type == 'L298N':
            # Use provided pins or defaults
            pins = DEFAULT_L298N_PINS.copy()
            pins.update(kwargs)
            
            self.driver = MotorDriver(
                in1=pins['in1'],
                in2=pins['in2'],
                ena=pins['ena'],
                in3=pins['in3'],
                in4=pins['in4'],
                enb=pins['enb'],
                pwm_freq=kwargs.get('pwm_freq', DEFAULT_PWM_FREQ)
            )
            print(f"[MotorController] Initialized with L298N driver")
            print(f"[MotorController] Pins: IN1={pins['in1']}, IN2={pins['in2']}, ENA={pins['ena']}, "
                  f"IN3={pins['in3']}, IN4={pins['in4']}, ENB={pins['enb']}")
            
        elif driver_type == 'IBT':
            # Use provided pins or defaults
            pins = DEFAULT_IBT_PINS.copy()
            pins.update(kwargs)
            
            self.driver = IBTMotorDriver(
                m1_rpwm_pin=pins['m1_rpwm_pin'],
                m1_lpwm_pin=pins['m1_lpwm_pin'],
                m2_rpwm_pin=pins['m2_rpwm_pin'],
                m2_lpwm_pin=pins['m2_lpwm_pin'],
                m1_r_en_pin=pins.get('m1_r_en_pin'),
                m1_l_en_pin=pins.get('m1_l_en_pin'),
                m2_r_en_pin=pins.get('m2_r_en_pin'),
                m2_l_en_pin=pins.get('m2_l_en_pin'),
                pwm_freq=kwargs.get('pwm_freq', DEFAULT_PWM_FREQ)
            )
            print(f"[MotorController] Initialized with BTS IBT_2 driver")
            print(f"[MotorController] Pins: M1_RPWM={pins['m1_rpwm_pin']}, M1_LPWM={pins['m1_lpwm_pin']}, "
                  f"M2_RPWM={pins['m2_rpwm_pin']}, M2_LPWM={pins['m2_lpwm_pin']}")
        else:
            raise ValueError(f"Unknown driver type: {driver_type}. Use 'L298N' or 'IBT'")
    
    def _smooth_speed_change(self, target_speed: int):
        """
        Gradually change speed to target (if smooth acceleration is enabled).
        
        Args:
            target_speed: Target speed (0-100)
        """
        if not ENABLE_SMOOTH_ACCELERATION:
            self.current_speed = target_speed
            return
        
        # Gradually increase or decrease speed
        while self.current_speed != target_speed:
            if self.current_speed < target_speed:
                self.current_speed = min(self.current_speed + ACCELERATION_STEP, target_speed)
            else:
                self.current_speed = max(self.current_speed - ACCELERATION_STEP, target_speed)
            
            time.sleep(ACCELERATION_DELAY)
    
    def forward(self, speed: Optional[int] = None, duration: Optional[float] = None):
        """
        Move forward at specified speed.
        
        Args:
            speed: Speed (0-100), defaults to DEFAULT_FORWARD_SPEED
            duration: Optional duration in seconds (blocks until complete)
        """
        if speed is None:
            speed = DEFAULT_FORWARD_SPEED
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
